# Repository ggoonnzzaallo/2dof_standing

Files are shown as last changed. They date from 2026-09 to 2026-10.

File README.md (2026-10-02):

# Self-righting arm — design package

Current purchased architecture: **XIAO nRF52840 Sense + two PTK 7465 MG servos + one 500 mAh, 1S LiPo**. The user reported all parts ordered on 1 October 2026; see [procurement status](docs/PROCUREMENT_STATUS.md). Train on a computer with MuJoCo and Stable-Baselines3 PPO; run the small exported actor on the XIAO. The **IMU and LiPo charger are already on the XIAO Sense board**, which is attached to the robot's base. No boost converter, external IMU, servo driver board, or separate charger is planned.

This is a prototype design, not a proven self-righting product. **The revised CAD centers the battery, middle link and paddle over the base, surrounds each servo with a matching front-and-rear cage, and supports the far side of each joint with a passive bearing and pin. The delivered non-W servo, OEM horns and battery must be measured before final printing.** The two bearings and pins are proposed additions, not in the user's reported orders. The simulator's servo dynamics and masses are still unmeasured placeholders, not PTK characterization. No physical robot has been assembled or tested, and no trained recovery policy is included. The low-voltage motor cutoff, USB charge interlock, and 100 mA charge-current configuration described in `HARDWARE.md` are firmware requirements, not implemented code yet; implement and test them before untethered battery runs or relying on in-robot USB charging for the 500 mAh pack.

## Package

- [Current PTK parts list and fastener plan](BOM.md)
- [Ordered-parts status and incoming checks](docs/PROCUREMENT_STATUS.md)
- [Controller comparison and IMU location](docs/CONTROLLER_DECISION.md)
- [Servo choice versus SO-100 smart servos](docs/SERVO_DECISION.md)
- [Historical AliExpress shopping plan](docs/ALIEXPRESS_SOURCING.md)
- [Historical DigiKey sourcing audit](docs/DIGIKEY_SOURCING.md)
- [Wiring, commissioning, and design rationale](HARDWARE.md)
- [Onboard voltage monitoring and USB-C charging plan](HARDWARE.md#battery-monitoring-and-charging)
- [Power budget and brownout acceptance test](HARDWARE.md#power-budget-and-brownout-check)
- [CAD assembly](cad/assembly.step), [preview](cad/preview.png), [servo-mount fit coupon](cad/servo_mount_fit_coupon.stl), [horn fit coupon](cad/horn_fit_coupon.stl), [pivot fit coupon](cad/pivot_fit_coupon.stl), [battery-tunnel fit coupon](cad/battery_tunnel_fit_coupon.stl), [measurement sheet](cad/FIT_CHECK.md), and [CAD/printing notes](cad/README.md)
- [Training and deployment pipeline](sim/README.md)
- [Software validation results](sim/validation.json) and [sampled CAD motion check](cad/motion_check.json)

## Design decisions

The serial hinges are **perpendicular**: lower X axis, upper Y axis. Two parallel hinges would concentrate motion in one plane and make general sideways recovery much harder. The supplied reference XML also uses perpendicular axes. The base is free to translate and rotate; it is not attached to the table. Once recovered, the robot stands on a stable platform rather than continuously balancing on an edge. [Reference project](https://github.com/homemadegarbage/SelfRisingRobot), [project article](https://homemadegarbage.com/rl13).

The base footprint remains **70 × 64 mm**; the full upright envelope is about **70 × 66 × 145 mm** because the upper servo cage projects just past one base edge. The joints are at 42 and 87 mm. A centered tunnel under the mounting deck holds the battery; the XIAO and power switch sit on opposite low shelves. The separate battery guard is no longer needed. The earlier **80–90 g** estimate predates the centered, caged structure and must be rechecked from sliced and measured masses. The parametric design allows shrinking after the recovery mechanics are demonstrated.

The [XIAO Sense](https://wiki.seeedstudio.com/XIAO_BLE/) is 21 × 17.8 mm and combines an nRF52840, six-axis IMU, battery input and LiPo charger. It has enough memory for the provided 4,994-parameter actor: **19,976 bytes of float32 weights** plus small working buffers. This is inference only; training stays on the workstation. Select SKU **102010469**; similarly named XIAO boards have different sensors.

The reference [ATOM Matrix](https://docs.m5stack.com/en/core/ATOM%20Matrix) **also has its IMU onboard** and the author reports running the build on a 3.7 V cell. Its documented input is 5 V, and its board documentation does not list an onboard LiPo charger. For this version, the XIAO offers a smaller board footprint and integrated charging; the ATOM retains advantages for reproducing the author's firmware and Wi-Fi user interface. The [detailed comparison](docs/CONTROLLER_DECISION.md) separates verified specifications from prototype assumptions.

The [reference robot](https://homemadegarbage.com/rl13) used PTK 7465 MG servos from one 3.7 V LiPo; the author confirms operation without a boost converter in the article comments. This is direct evidence for the same kind of recovery task, but **not** a manufacturer's 1S operating guarantee. Confirm the exact received servo variant, test it at 4.2, 3.8 and 3.6 V, and update the CAD and simulation with measured dimensions and dynamics before relying on the design.

## Evidence and limits

All three robot-part STLs and four fit-coupon STLs pass watertight-mesh and single-connected-component checks; see `cad/stl_validation.json`.

The provisional PTK CAD solids export successfully; each printed part and fit coupon is one valid connected solid. The upright assembly has no unintended rigid-envelope overlaps. An 81-pose grid over both joints at 20-degree increments from −80 to +80 degrees found no clashes in the checked bodies, bearings and pins. This is **not** a continuous clearance certificate: actual horns, screw heads, nuts, leads, compliance and manufacturing tolerances still require inspection.

The earlier Gymnasium environment check, 1,500 randomized steps and short 512-step PPO training smoke test passed before the PTK geometry update. Exported C inference then agreed with SB3 deterministic inference to better than 1e-5 on 100 test observations. That smoke policy was discarded; the centered `sim/robot.xml` has only been loaded and briefly stepped in MuJoCo, not retrained or rechecked end-to-end.

The next physical milestones are: fit the supplied servo horns; measure travel/torque/lag at 4.2, 3.8 and 3.6 V; demonstrate a scripted rise from each major fall direction; update the model; then train and transfer. If scripted recovery is mechanically impossible from a resting pose, change the contact geometry before spending time on RL.

The USA distributor prices and listing availability in the [earlier FT90M estimate](docs/FT90M_BOM_HISTORY.md) were checked on **27 September 2026**. They are historical estimates, **not the actual cost of the ordered PTK build**. The capacitor and signal resistors remain optional diagnostic additions. The confirmed Pololu and battery order totals, and the still-unknown delivered costs of other purchases, are recorded in [procurement status](docs/PROCUREMENT_STATUS.md).

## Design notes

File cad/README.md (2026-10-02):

# CAD — centered PTK 7465 MG prototype, millimetres

`assembly.step` includes three original printed parts and simplified purchased-part envelopes. Import STEP into Fusion, SolidWorks, FreeCAD or Onshape. The parametric source is `build_cad.py` (CadQuery; generated and checked using 2.8.0). This is newly constructed geometry, not copied from the reference STL files. This revision centers the battery and both moving links over the base, brings each passive bearing support closer to its servo horn, and uses the same two-sided printed cage at both servos.

The CAD now uses a **PTK 7465-family envelope**, but the only dimensioned illustration located is labeled **7465W MG**; the ordered servo is **7465 MG (non-W)**. The [manufacturer's related MG-D listing](https://www.ptkhobby.com/en/sys-pd/234.html) gives the same 23.9 × 12 × 26.6 mm class and 25T output, while the [dimensioned 7465W illustration](https://manuals.plus/ae/1005008789583991) shows a 23.8 mm body, 12 mm width, 31.8 mm ear span, about 27.8 mm mounting pitch, 22 mm main case depth and 30.1 mm overall height including spline. These are **provisional dimensions**, not a verified drawing of the received non-W units. The horn face, boss and mounting interface still require caliper checks. The generated STEP/STL files are a reviewable starting point, not a print-and-assemble guarantee.

| Print one each | Export | Notes |
|---|---|---|
| Base with centered battery tunnel, lower-servo cage and outboard bearing cheek | `base.step`, `base.stl` | Lower plate on bed; the tunnel roof and both cage hoops may need bridging support. Test the cage coupon first. |
| Centered middle link with rotated copy of the servo cage, lower journal and upper outboard cheek | `middle_link.step`, `middle_link.stl` | Stout rounded 12 × 14 mm spine; orient for strength at the lower disk, cage rails and upper fork. |
| Centered upper paddle / horn adapter with outboard journal | `paddle.step`, `paddle.stl` | Rounded 16 × 10 mm shaft and 22 mm wide tip; support the adapter step as needed. |

Four disposable test pieces are generated: `servo_mount_fit_coupon.step/.stl` reproduces the complete front-and-rear servo cage; `horn_fit_coupon.step/.stl` reproduces the adapter face, center access and four radial slots; `pivot_fit_coupon.step/.stl` contains a bearing seat and a separate blind pin bore; `battery_tunnel_fit_coupon.step/.stl` is a 22 mm long tunnel cross-section to test pack clearance and roof bridging. Print the relevant coupons after the servos, battery and proposed pivot hardware arrive, and fill the [incoming measurement sheet](FIT_CHECK.md). The coupons are **not** installed on the robot.

STLs retain the assembly coordinates. Use the slicer's place-on-bed/orient tools for each part; they are not prearranged on a print plate. Start with a 0.4 mm nozzle, 0.2 mm layers, at least 4 walls and 30–40% infill in PLA+ or PETG. Each cage has a front mounting hoop, a rear collar and two 3.5 × 8 mm side rails connecting them; the upper cage is the same geometry rotated 90°. The rear is open for the servo lead, while the side gaps expose the case and mounting fasteners. The lower post and upper cheek have 5 mm axial thickness with tapered roots. Inspect layer direction at cage-to-deck/web joints, disk-to-spine transitions and bearing cheeks. These dimensions improve the load path but have **not** been stress-tested or checked by FEA. Use actual sliced masses in simulation; CAD solid volumes are not printed masses.

The base footprint is 70 × 64 mm; the full upright assembly is approximately **70 × 66 × 145 mm** because the upper servo and rear collar project just past the −Y base edge. Joint origins are `(0,0,42)` and `(0,0,87)` mm; axes +X then +Y at neutral. Both servo assemblies shift 18 mm inward along their output axes, so the moving spine, paddle, battery and joint axes all lie over `(x,y)=(0,0)`. Both cage body openings use **23.9 × 12.0 mm nominal** plus **0.3 mm per-side clearance**; the provisional flange-hole pitch is **27.8 mm**, and the nominal output-axis offset is **6.0 mm** toward one end of the case. These are parameters in `build_cad.py`, not fixed measured truths. Neither SG90 nor FT90M horns are interchangeable with the likely PTK **25T ~5 mm** spline; use the included PTK OEM horns.

The battery slides into the center tunnel from the +X end. Its provisional envelope is 59.5 × 19 × 7.5 mm; the tunnel is 21 mm wide and 10 mm tall above the 3 mm floor, with an end stop at −X. A small cable tie through the two windows at +X retains the pack **at its end**, without squeezing the pouch. The XIAO Sense sits on the +Y low shelf and the Pololu switch on the −Y shelf. This removes the separate battery-guard print. Check the received cell, connector and lead bend radius before final printing; the battery must slide in and out without force. Add insulation under both boards and strain-relieve moving wires.

**Fit-check parameters:** the assumed OEM horn face is 16.5 mm in the original servo-local coordinates; after the 18 mm inward shift, `HORN_FACE=-1.5 mm` in robot coordinates. This is still unmeasured. The now **28 mm diameter, 3 mm thick** printed disk has a 6.8 mm center opening and four radial 2.2 mm slots for a drilled OEM cross/double horn. Use two opposed lateral slots, not the slot under the beam. Each disk has a 12 mm diameter outer hub with a blind 3.05 mm nominal bore for a 3 × 12 mm pin. The fixed cheek has an 8.05 mm nominal bearing pocket, 3 mm deep, with a 6.2 mm rear relief so the shoulder clears the rotating inner race and seats near the outer race. Fit-check horn thickness, slot-to-horn-hole location, screw length, nut/washer clearance, center-screw access, wire exit and spline engagement on physical hardware. Do not print a replacement spline or force a center screw with an unverified thread.

The support is **coaxial** with each servo output: the lower bearing cheek is part of the base and its pin is in the middle link; the upper cheek is part of the middle link and its pin is in the paddle. The pin rotates with its link while the bearing outer ring stays with the parent. This creates a second radial support point across the joint, relieving bending at the servo spline and horn. It is a supported shaft, not a literal double-shear fastener. The upper cheek rises directly from a tapered root on the centered spine, with no long side bridge. The added material changes mass and inertia; use sliced and then measured masses in the simulator.

**Assembly order:** before attaching a horn, slide each servo body into its cage from the output side until the ears meet the front hoop. Route the lead out the open rear; check that its strain relief clears the rear collar without a tight bend. Fasten both ears through the hoop, then install the OEM horn and center screw while there is still straight-on access. The printed outer hub blocks that screwdriver access after assembly, so attach the printed adapter to the horn with its two lateral screws afterward. Seat the bearing by pressing only on its outer ring; if the pocket is loose, retain the **outer ring only** with a small amount of suitable adhesive. Trial-fit the pin to the bearing, then retain the pin in the printed blind hub with a controlled press fit or a tiny amount of suitable adhesive after confirming smooth rotation. Keep adhesive out of the races. The pin should not bottom against the bearing or clamp its inner race axially; trim or change pin length if actual dimensions demand it. Both 3.05 and 8.05 mm printed bores are nominal CAD dimensions, not validated printed fits.

On receipt, measure and record: case length/width/depth; ear span and hole centers/diameters; output-axis offset from the case center; flange face from the back; boss and shaft projection; rear lead and strain-relief envelope; OEM horn arm thickness, radius and hole diameter; OEM center-screw thread/length. Adjust the parameters and rerun the generator before final printing. Check both servos in the full cage coupon: small manufacturing or variant differences matter at a 0.3 mm nominal cavity clearance.

The regenerated **provisional** assembly has no nominal volume intersections in `nominal_clashes.json`. `motion_check.json` checks 81 configurations at 20-degree increments across ±80 degrees, including the outboard bearing and pin envelopes; it does not check a continuous sweep or the real horns, fasteners, leads, ties or print tolerances. Passing this check is not a guarantee of a usable motion range or physical recovery.

The two bearings and pins remain **proposed additions, not included in the user's reported orders**. The centered layout adds no new electrical components. Review it against the delivered PTK horns and battery before buying or printing the full arm. The battery tunnel and wider links add material, so scripted recovery and 1S servo margin still need physical testing.

Regenerate with a separate CAD environment:

```sh
python3.12 -m venv .venv-cad
.venv-cad/bin/pip install cadquery==2.8.0 matplotlib
.venv-cad/bin/python cad/build_cad.py
.venv-cad/bin/python cad/check_motion.py
.venv-cad/bin/python cad/render_preview.py
```

Keep the CAD and training environments separate; their NumPy dependency ranges differ.

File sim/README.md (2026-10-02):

# Training and deployment pipeline

**Centered PTK revision:** `robot.xml` places the battery below the deck, moves the joints to 42 and 87 mm, centers the two moving links, and uses nominal 13 g servo masses. The CAD now also has a front-and-rear printed cage around each servo; its added mass and contact shape are not yet reflected in this primitive model. Weigh and measure the printed assemblies before the transfer-training pass. Servo speed, torque, lag and current behavior at 1S voltage have **not** been measured; `environment.py` retains exploratory placeholder dynamics. Do not train a transfer policy from those numbers until the delivered servos and assembled geometry are characterized.

Use **MuJoCo + Gymnasium + Stable-Baselines3 PPO**. The two-action, small-MLP problem does not justify changing to a GPU robotics stack before basic recovery is demonstrated. SB3 recommends CPU operation for its MLP PPO workloads and supports multiple environments. [Official PPO documentation](https://stable-baselines3.readthedocs.io/en/master/modules/ppo.html), [MuJoCo simulation documentation](https://mujoco.readthedocs.io/en/stable/computation/index.html).

## Supplied runnable starter

- `robot.xml`: free-base, two perpendicular hinges, floor contacts, approximate component masses and primitive collision shapes. Its main joint, paddle, battery, board and switch positions track the centered CAD. The battery tunnel, bearing cheeks, adapters, fasteners and contact details are simplified; it is **not an exact digital twin**. Parent-child collision filtering and physical joint limits must be reviewed as the geometry is finalized.
- `environment.py`: 2 ms physics, 20 ms policy steps; finite torque/speed/lag; command delay, mass, friction and IMU noise randomization; upright, side, diagonal and inverted resets.
- `train.py`: SB3 PPO with separate 64×64 tanh actor/critic, CPU and optional subprocess environments.
- `export_actor.py`: actor-only C export, no neural-network runtime required.
- `check.py`: environment validation, random rollout, short training smoke test, and compiled C-vs-SB3 parity test.
- `validation.json`: actual check results. No useful trained controller has been produced.

From this package's root:

```sh
python3 -m venv .venv-sim
.venv-sim/bin/pip install -r sim/requirements.txt
.venv-sim/bin/python sim/check.py
.venv-sim/bin/python sim/train.py --envs 4 --steps 2000000 --out runs/ppo_seed1
.venv-sim/bin/python sim/export_actor.py runs/ppo_seed1.zip policy.h
```

The version pins record the tested environment rather than a claim that these are the newest releases. The default two million steps is a starting budget, not a convergence prediction. Repeat with independent seeds. The C compiler is required only for `check.py`'s host parity check.

## The servo is not an ideal angle source

The policy sends **target-angle changes**, not joint angles or motor torque. In `environment.py`, each command first passes through 0–40 ms of randomized delay. An internal servo target moves toward it at a finite rate. The simulated servo then compares that target with the **actual simulated joint angle and velocity** and applies a bounded torque; floor contact or gravity can make the joint lag, stall, or be pushed away from the target. This mirrors the division of work on the robot: the PTK servo closes its own position loop, while the XIAO only knows the angle it requested. Actual simulated joint angle is used inside the servo physics and training reward, **not as an input to the policy**.

The present **3–5 rad/s** speed, **0.045–0.070 N·m** torque, gain and delay ranges are placeholders, not measurements of PTK 7465 MG on one LiPo cell. The [related manufacturer's MG-D data](https://www.ptkhobby.com/en/sys-pd/234.html) only give speed at 5 V and above; they do not predict motion at 3.6–4.2 V while pushing against the floor. Before substantial training, mark a horn and film repeatable angle steps from a fixed camera at several battery voltages, first unloaded and then with a representative link/load. Fit command delay, joint angle versus time, steady tracking error and reversal deadband/backlash. Use a known lever/load and brief current measurements to bound usable torque without holding the servo stalled. Temporary video gives angle/speed measurements for calibration; the finished robot does not need joint sensors merely to calibrate the simulator. Compare real and simulated traces for held-out commands, then randomize parameters around the measured range. If large unobserved joint deviations still defeat recovery, consider feedback hardware and retrain with its angle readings.

## Observation/action contract

The 10 float32 inputs, in order, are:

| Indices | Value on both simulator and MCU |
|---|---|
| 0–2 | Unit DOWN vector in the base frame: `R_world_from_base.T @ [0,0,-1]`; upright is `[0,0,-1]` |
| 3–5 | Base-frame gyro in rad/s divided by 10, clipped to ±1 |
| 6–7 | Last commanded target angles divided by 1.3963 rad, clipped to ±1 |
| 8–9 | Previous clipped policy action |

Two outputs are clipped to ±1, multiplied by 0.06 rad and added to the stored joint targets each 20 ms. Clamp targets to ±1.3963 rad (±80°). Convert targets to calibrated servo pulse widths in firmware. Initial targets/actions are zero. Input scale/order, angle signs, timing and hidden-state initialization must match exactly.

There is no `VecNormalize` state to forget during export. The export preserves SB3's deterministic Gaussian mean and final action clipping; it does not introduce an extra output tanh. The actor contains 4,994 floats (19,976 bytes), about 4,864 multiply-accumulates per call plus tanh operations. It fits the proposed MCU comfortably in memory; measure worst-case execution time on the real firmware before committing to 50 Hz.

Actual joint angle and velocity are used for simulated servo dynamics and reward, **not policy observations**, since the selected three-wire PTK servos do not report them. Floor contact is likewise used to score success during training, not passed to the policy. It is fine for a simulator to use these privileged quantities for its reward: the deployed policy only runs inference and does not calculate that reward. A future feedback-servo upgrade requires a changed wiring/model/observation contract.

## Real training sequence

1. **Identify the hardware.** Weigh assemblies and measure COM. Record pulse-to-angle curves, sign, endpoints, no-load and loaded step responses, backlash, battery sag and current at 4.2/3.8/3.5 V. Fit servo dynamics and bound torque; stall torque is not continuous torque.
2. **Make a demonstrably recoverable mechanism.** Find slow scripted or short waypoint sequences for cardinal and diagonal falls. Search safe sequences in simulation, then test under supervision. If necessary change base width, paddle reach or contact shape. Preserve a simple scripted baseline.
3. **Build the simulation fidelity that matters.** Replace primitive contacts with a sensible decomposition of measured printed parts; do not use a single convex hull that fills the arm's open spaces. Match joint stops, base edges, battery deck and bearing-cheek contacts. Retain the floating root. Confirm real and simulated step responses before policy optimization.
4. **Use curriculum if scratch PPO stalls.** Start near upright, then side falls, then inverted starts. Optionally behavior-clone successful scripted trajectories into the actor, then call PPO `.learn(...)` to optimize further. The source project's search/demo-pretrain workflow is useful, but its saved model is not interchangeable with our changed geometry and observations. [Reference repository](https://github.com/homemadegarbage/SelfRisingRobot).
5. **Randomize within measured bounds.** The starter includes mass ±10%, floor friction 0.35–1.0, torque 0.045–0.070 N·m, speed 3–5 rad/s, gain, 0–40 ms command delay and sensor noise. These are placeholder ranges. Add measured backlash/deadband, COM uncertainty, battery-dependent behavior and observation delay before transfer. Avoid deliberately training on physically impossible torque.
6. **Evaluate separate from training.** Use held-out seeds; four side falls, four diagonals, inverted starts and multiple initial joint states; test several surfaces and voltages. Log recovery success within 10 s, recovery time, peak current, stalls and peak contact loads. Require sustained base uprightness, near-home arm, low angular velocity and floor contact. Do not count an airborne or tip-balanced instant as success.
7. **Deploy and compare logs.** Run IMU acquisition/fusion around 200 Hz, policy/PWM target update at 50 Hz. Export only the actor and compare known input/output vectors on the MCU. Then start with restricted motion and expand toward the validated envelope.

## IMU and sim-to-real details still to implement

**The current environment is a software starter, not yet sensor-faithful for transfer.** Its gravity observation comes from MuJoCo's exact base orientation plus noise, while the real robot has only one base-mounted accelerometer/gyro. Real hardware needs a quaternion-based gyro/accelerometer attitude filter and explicit sensor-to-base alignment; the environment must then use the same estimator or model its delay and dynamic errors before training a deployment policy. A normalized raw accelerometer reading is not gravity during a flip. Gate accelerometer correction during strong non-gravitational acceleration, and test recovery through 180-degree orientations. Avoid a roll/pitch formula that changes branches or saturates at 90 degrees. The IMU cannot directly see joint angle, contact or absolute yaw; upright recovery should not depend on absolute yaw.

The 10-input starter has no history or battery observation. If real servo lag creates partial observability, add a short observation history first (and update the exporter), or a battery-voltage feature after calibrating the ADC. A recurrent policy is an option, but makes deployment and reset behavior more complicated. Do not change observation dimensions only on one side.

Firmware board support, sensor filter, PWM calibration, battery sensing, arming, watchdog and servo-power sequencing remain to be implemented. The portable policy exporter is supplied and tested; a board-ready firmware image is not part of this prototype package.

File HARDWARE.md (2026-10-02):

# Hardware and commissioning

**Servo revision (1 October 2026):** Two PTK 7465 MG servos have been ordered. The CAD now uses a provisional PTK 7465-family envelope. The actual non-W servo's mounting ears, horn, pulse mapping, 3.3 V signal response and one-cell current/torque remain incoming checks. The electrical topology below is unchanged. See [procurement status](docs/PROCUREMENT_STATUS.md).

The IMU is the LSM6DS3TR-C chip **on the XIAO nRF52840 Sense PCB**. Mount that PCB rigidly on the base, near the controller envelope shown in `cad/assembly.step`. There is no separate IMU module or IMU wire harness. The reference ATOM Matrix also contains its own IMU (MPU6886). See the [board comparison and parts-count options](docs/CONTROLLER_DECISION.md).

## What the robot can measure

| Device | Available to the XIAO | Role |
|---|---|---|
| **One** onboard LSM6DS3TR-C IMU | Three-axis acceleration and three-axis angular velocity | Estimate base orientation relative to gravity and its rotation rate. Six axes means two three-axis measurements, **not six IMUs**. The IMU is rigidly attached to the base, so it does not directly measure either moving link. [Seeed IMU guide](https://wiki.seeedstudio.com/XIAO-BLE-Sense-IMU-Usage/). |
| XIAO battery-voltage ADC divider | Cell voltage after calibration | Low-battery protection and optional policy input; not a joint or contact sensor. See battery-monitoring details below. |
| Two PTK 7465 MG servos | Commanded PWM targets only | The selected three-wire servos expose signal, power and ground, with no shaft-angle, velocity, load, current or battery-voltage telemetry to the XIAO. They control their own position internally. [PTK's related 7465 MG-D page](https://www.ptkhobby.com/en/sys-pd/234.html). |
| XIAO Sense onboard microphone | Present but unused | It is not required for upright recovery or the current policy. [Seeed board specification](https://wiki.seeedstudio.com/XIAO_BLE/). |

This sensor set is enough to **attempt** the current ten-input policy because its inputs are base gravity direction and angular rate, the last two commanded joint targets and the previous two actions; actual joint angles and contact state are deliberately excluded. It is not full-state feedback. A stalled, back-driven or lagging servo can be far from its commanded target without the controller knowing. If measured recovery trials show this matters, the first sensor upgrade should be two joint-position feedback channels or servos that expose angle telemetry, rather than a second base IMU. Such a change also requires updating the policy observation and training model.

If command-only observations prove insufficient after physical trials, joint feedback would require a different servo or carefully characterized modification. That would change the wiring, observation vector, model and CAD. It is not part of the ordered Rev A hardware; see [servo tradeoffs](docs/SERVO_DECISION.md).

## Power and signals

```text
EFLB5001S25 1S battery / keyed RCY connector
  + ----+---------------------------- XIAO BAT+
        +---- Pololu 2810 VIN
                   VOUT ----+-------- Servo 1 positive
                            +-------- Servo 2 positive
  - ----+---------------------------- XIAO BAT- / GND
        +---------------------------- Pololu GND
        +---------------------------- Both servo grounds

XIAO D0 ---------------- Servo 1 signal
XIAO D1 ---------------- Servo 2 signal
XIAO D2 ---------------- Pololu ON
USB-C ------------------ XIAO programming + onboard charging
```

**The servos are not powered by the XIAO.** At the RCY pigtail, split battery positive into a thin XIAO BAT+ branch and a separate, short power branch through the Pololu switch to both servo red leads. Split battery negative into XIAO BAT−/GND and both servo black/brown leads at the same battery-side junction. Only the two servo signal leads and the switch's ON control lead connect to XIAO GPIOs. The shared ground gives those signals a common reference; the motor current returns directly to the battery junction, not through the controller board. Never connect servo red leads to XIAO 3V3 or 5V/VBUS, and do not route motor current through tiny PCB traces or a solderless breadboard.

Keep the high-current wiring short and secure. No external capacitor or signal resistors are planned in the first wiring layout. Measure the battery voltage at the controller during hard servo direction changes; add a capacitor across the switched servo supply only if measured transients or resets justify one. A capacitor cannot rescue an undersized battery or long resistive power wiring. [Pololu notes that capacitors near its switch can reduce spikes when interrupting large currents](https://www.pololu.com/product/2810).

Leave the **Pololu's physical slide OFF permanently** for normal MCU control; no routine slide movement is needed, including for USB charging. On this particular switch, physical OFF is **not a manual motor disconnect**: D2 HIGH still powers the servos. Physical ON forces them on, overriding D2. With physical OFF and D2 LOW or floating, the servo rail is off. Initialize D2 LOW before any PWM setup. Before cutting servo power, stop both PWM outputs and set their pins low; keep them low until servo power is restored. This avoids intentionally driving an unpowered servo through its signal pin. Check the actual servos for back-powering; two optional 1 kΩ series resistors can limit that current if it occurs, but do not replace correct sequencing. [Pololu 2810 documentation](https://www.pololu.com/product/2810).

## Battery monitoring and charging

**The XIAO Sense can read the battery without extra hardware.** Its onboard voltage divider presents a reduced battery voltage to ADC pin **P0.31**; drive **P0.14 LOW** to enable that reading. The reviewed schematic uses 1 MΩ/510 kΩ divider resistors, but board revisions and ADC settings can change the conversion, so calibrate the reported volts against a multimeter at the actual BAT pads. Do not assume a raw ADC count is directly the cell voltage. [Seeed's pin/charging documentation](https://wiki.seeedstudio.com/XIAO_BLE/) specifically warns that driving P0.14 HIGH can put P0.31 at its input limit during charging; keep P0.14 LOW while reading and never drive it HIGH while charging. Raw Nordic pin names are not necessarily Arduino D-pin numbers. The PTK servos have ordinary PWM command inputs and **no battery-voltage telemetry**; their three wires cannot report cell state.

The planned firmware will sample battery voltage during servo operation, filter out single-sample noise, and latch a low-battery fault if the voltage at the XIAO falls below an initial **3.6 V loaded threshold** for a short sustained interval. On fault it will stop PWM, pull D2 LOW to disconnect servo power, indicate the fault with the XIAO's onboard LED, and sleep. The threshold and filtering require calibration from the loaded bench test below. The ADC is adequate for tracking pack voltage and triggering a cutoff, but voltage under variable servo load is **not a precise charge-percentage gauge**; it can also miss millisecond dips. **This cutoff firmware has not yet been implemented.** The battery remains connected to the MCU when servos are disabled; **unplug the RCY for storage and a true power-off**.

**Routine charge without unplugging the battery:** the XIAO's [BQ25101 single-cell charger](https://www.ti.com/product/BQ25101) charges the connected pack toward **4.2 V** through the robot's USB-C port. The Pololu slide stays physically OFF. Charge-mode firmware must stop servo PWM, command D2 LOW, and keep the servo rail disabled whenever USB VBUS is present. The nRF52840 supports [USBDETECTED/USBREMOVED events](https://docs.nordicsemi.com/r/bundle/ps_nrf52840/page/usbd.html) without another sensor component. Verify that servo VOUT is off during bring-up. Merely putting the slide in OFF is insufficient if D2 remains HIGH. If the servo rail remains on, the servos can move and draw from the battery while charging, delaying charge completion or triggering the charger's fixed ten-hour safety timer. It does not route servo current through the XIAO, but it is not the intended charge state. **The charge interlock firmware is not yet implemented**, so do not rely on automatic motor shutoff in the present prototype.

For in-robot charging, [Seeed documents](https://wiki.seeedstudio.com/XIAO_BLE/) configuring **P0.13 as an output driven LOW** for approximately **100 mA**, or as a high-impedance input without pulls for approximately **50 mA**. In a Seeed Arduino-core sketch, the 100 mA setup is `digitalWrite(P0_13, LOW); pinMode(P0_13, OUTPUT);`; keep that state for the charging session. This is a firmware setting, not a physical switch or battery-voltage sense pin. At 100 mA (0.2C), an empty 500 mAh pack needs at least about five hours plus the voltage-taper phase. The 50 mA setting is approximately 0.1C and could hit the [charger's fixed ten-hour safety timer](https://www.ti.com/product/BQ25101) before completing. The charger IC itself is specified for a maximum of **250 mA**, and Seeed exposes only the approximately 50/100 mA settings on this board, so **500 mA cannot be selected by software on the XIAO**. The XIAO's charge LED indicates charging activity; verify final battery voltage rather than treating the LED alone as a complete fuel gauge. **Do not apply battery voltage to 3V3 or 5 V to BAT.** Unplug the RCY only for long-term storage or a true hardware power-off, not for routine charging.

## Power budget and brownout check

Seller data for the [PTK 7465 MG family](https://manuals.plus/ae/1005008789583991) reports about **1 A stall current per servo at 4.8 V**. That is only a provisional sizing comparison for two servos (about 2 A), **not** a measurement or guaranteed limit for the purchased non-W units at 3.6–4.2 V. The selected [500 mAh, 25C battery](https://www.horizonhobby.com/product/1s-3.7v-500mah-25c-li-po-battery-jst-rcy/EFLB5001S25.html) advertises a nominal 0.5 Ah × 25 = **12.5 A discharge rating**, above the comparison load on paper. A C rating does not specify voltage sag at the board, connector loss, cell aging, or how long the servos can sustain a mechanical stall. Measure peak draw and sag with the actual pair.

The [Pololu 2810 LV switch](https://www.pololu.com/product/2810) is rated for single-cell voltages and lists 3 A continuous at its 55 °C reference point. The XIAO's [schematic](https://files.seeedstudio.com/wiki/XIAO-BLE/Seeed_Studio_XIAO_nRF52840_PDF.pdf) instead shows a **3.3 V, 250 mA regulator** for its electronics. This is why the servo-power split must occur **before** the XIAO: two servos would exceed that regulator by a wide margin. The regulator also needs input headroom; when the shared battery sags near the end of a run, the 3.3 V rail can dip even though the motors do not draw through the board. The [regulator datasheet](https://www.sg-micro.com/product/SGM2040) gives low dropout under specified conditions, but it does not guarantee behavior for this unmeasured battery/harness and simultaneous servo load.

For the first measurement, use a **DC multimeter**, two thin insulated temporary sense wires, and clips. With the battery **unplugged**, solder one sense wire to the XIAO-side BAT+ joint and one to its GND joint; insulate and strain-relieve both so no clip can short the tiny pads or snag a moving link. Put the meter in **DC-volts mode, in parallel** across those wires (red to BAT+, black to GND). Secure the robot's base, run a repeatable two-servo motion, and watch the voltage while the arms move. To check the regulated rail too, add a **third temporary sense wire to XIAO 3V3 while power is disconnected**, then repeat with the meter's red clip on that wire and black still on GND; a second meter lets you observe both at once. Do **not** use the meter's current/A jack across the battery. A meter with MIN/MAX is helpful for slow sag, but many meters miss millisecond dips. A two-channel oscilloscope at the same test wires is the follow-up tool if resets occur or exact transient minima matter. The robot's built-in battery ADC can log voltage during later untethered tests after calibration, but it can miss brief dips too. [Seeed documents the BAT measurement pins and the required P0.14 LOW state](https://wiki.seeedstudio.com/XIAO_BLE/).

Before untethered operation, test around 4.2, 3.8, and 3.6 V cell voltage while commanding both servos through the fastest intended reversals and brief high-load motions; do not hold a servo at stall. As a conservative prototype acceptance target, the **3V3 rail should stay above 3.2 V and the controller should never reset** during those tests. That 3.2 V value is a design target, not the chip's published reset threshold. If it fails, first improve the battery connector, wiring and cell choice or raise the loaded-voltage cutoff; then consider the optional capacitor for short transients. A capacitor will not fix sustained sag.

**Do not operate this design below 3.0 V at the cell.** The PTK servo's *published* lower operating limit is around **5 V** on the [manufacturer's related 7465 MG-D page](https://www.ptkhobby.com/en/sys-pd/234.html), so **all direct 1S operation is outside that rating**, despite the reference robot's 3.7 V success. The XIAO's 3.3 V regulator cannot maintain a 3.3 V output from a battery below 3.3 V, so a reset or unstable sensing is possible. The selected single-cell LiPo should be shut down well before 3.0 V; [Horizon Hobby's LiPo equipment guidance](https://www.horizonhobby.com/on/demandware.static/-/Sites-horizon-master/default/Manuals/EFLU02050_MANUAL_EN.pdf) uses a 3.0 V-per-cell low-voltage cutoff. Our initial **3.6 V loaded servo cutoff** is intentionally earlier to preserve regulator headroom and battery life, pending measurement. Raise that cutoff if recovery weakens sooner. The cutoff firmware is still a required implementation, and the battery should be disconnected for storage; do not assume the selected RC battery includes its own low-voltage protection.

Use a watchdog and explicit arming state. Charge/program mode, invalid sensor data, stale control loop and low voltage should leave D2 low. Start with a USB command to arm during bench development, then add a deliberate untethered arming gesture/button behavior. No wireless link is needed during normal operation.

## Why 500 mAh, and estimated runtime

The 500 mAh EFLB5001S25 was a **conservative prototype choice**, not the smallest proven pack. Its stated 25C discharge rating corresponds to 12.5 A on paper, above the PTK-family's approximate 2 A combined 4.8 V stall-current comparison. It has a matching RCY connector and dimensions for the current CAD, but at roughly 14.5 g and 59.5 × 19 × 7.5 mm it is a major driver of base size. The reference robot uses 220 mAh. A smaller, suitably high-discharge cell may be better after measuring actual recovery pulses and voltage sag.

Runtime cannot be predicted from stall current or capacity alone: it depends on how frequently the policy moves the joints, how hard it pushes on the floor, voltage sag, and the chosen 3.6 V loaded cutoff. The purchased PTK pair has **no verified 1S current profile**. [Seeed lists 10.38 mA](https://files.seeedstudio.com/wiki/XIAO/Seeed-Studio-XIAO-Series-SOM-Datasheet.pdf) for a normally running XIAO Sense. For planning only, assume **300–400 mAh usable** before the early voltage cutoff and divide that by measured *average total battery current*:

| Average current, including both servos and controller | Illustrative runtime to cutoff |
|---:|---:|
| 0.25 A | 1.2–1.6 h |
| 0.5 A | 36–48 min |
| 1.0 A | 18–24 min |

Those are arithmetic scenarios, **not measured endurance claims**. As a first planning range for repeated active recoveries, expect tens of minutes to about an hour, then replace this estimate with battery-side current logging over representative episodes. A stationary upright robot may last much longer. The 500 mAh pack also takes at least about five hours plus taper on the XIAO's 100 mA charger; a smaller cell would improve both size and charging time if it passes the loaded-voltage test.

## Servo selection and limits

The [manufacturer's related PTK 7465 MG-D page](https://www.ptkhobby.com/en/sys-pd/234.html) specifies a 23.9 × 12 × 26.6 mm package, 25T ~5 mm output spline and about 5–8.4 V operating range. Family listings report approximately **3.8 kg·cm stall torque** and **0.11 s/60° no-load speed at 5 V**; those are neither continuous torque nor 1S performance figures. The [reference robot](https://homemadegarbage.com/rl13) used PTK 7465 MG on one cell and the author reports 3.7 V worked without boost. Verify the purchased non-W units and XIAO's 3.3 V control signal on the bench. If the servos weaken unacceptably as the cell discharges, reconsider power architecture based on measurements.

The simulation's **0.045–0.070 N·m torque limit and 3–5 rad/s speed** are conservative design assumptions to replace with measurements. They are not manufacturer continuous-duty ratings. Avoid using the reference model's 1 N·m actuator limit for these micro servos.

PTK-family listings commonly describe **500–2500 µs for about ±90°**, but variant-specific center and endpoint settings differ. Start with the horn removed and a small **1450–1550 µs** sweep at 50 Hz; measure angle and direction, then widen gradually and set software stops for the actual mechanism. Do not assume the full advertised ±90° is safe with the printed links. The proposed robot joint range remains ±80° pending clearance and wire-loop checks. Later test whether a higher pulse refresh rate gives any benefit; a 50 Hz command rate matches the current policy loop.

These servos provide no external joint-angle feedback. Firmware stores commanded targets; it does not know the actual shaft angle under impact or stall. Training must model lag, backlash and load effects, and policy observations must not secretly use simulator joint encoders. The IMU belongs on the base so its orientation measures platform recovery.

## Mechanics and order of work

At a hypothetical 100 g assembled mass, a simple weight moment about a 35 mm base edge is approximately **0.034 N·m**. The centered reinforced design has not been weighed; this is a sizing example, not a mass prediction or proof that the actuator can execute a recovery trajectory. Floor contact, paddle reach, dynamic impulses and orientation can make the required joint torque much larger. The upper joint's job includes pushing on the floor, not merely lifting its own paddle.

1. Print the servo, horn and pivot fit coupons; check the case, flange holes, actual horn, bearing and pin. Measure the delivered battery as well. Correct CAD dimensions before printing the complete set.
2. Center one unloaded servo at its measured neutral. Install the correct OEM horn and output screw; establish angle direction and pulse calibration. Repeat for the second servo.
3. Assemble the two ear mounts and the two lateral horn adapters using the BOM. Keep screw ends and nut flats out of moving envelopes. Trim excess screw projection if required.
4. Slide the battery into the centered tunnel from the +X end. Retain it at the end with a tie through the two side-wall windows; do not compress or abrade the pouch. Secure the XIAO on the +Y shelf and the switch on the −Y shelf, insulate their undersides, confirm USB-C and slide access, and document sensor-axis orientation.
5. Wire and polarity-check with the battery disconnected. Test the MCU from USB first with the servo supply disabled. Then energize one servo on a current-limited bench supply, followed by both. Check voltage sag during direction reversals.
6. Test full intended travel slowly while supported. Then try four cardinal side falls, diagonal falls and inverted starts on a controlled surface. Start with scripted slow motion and a small search over safe waypoint sequences.
7. Weigh each moving assembly, measure COM, current, loaded response and floor friction. Feed those values back into MuJoCo before substantive policy training.

The base does not have arbitrary soft rubber feet: their traction and compliance would change the contact model. Begin on one repeatable hard surface, then randomize/test additional surfaces. The paddle contact edge and base width are the main geometry tuning parameters. If a pose wedges into a stable resting configuration from which neither joint can create a useful contact force, redesign that geometry; RL cannot remove the physical constraint.

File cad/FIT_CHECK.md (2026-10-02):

# PTK 7465 MG incoming fit check

This sheet distinguishes **provisional CAD inputs** from dimensions measured on the two delivered non-W servos. Fill both measured columns before changing `build_cad.py` or printing the final base and link. The 7465W drawing and related MG-D page are useful family references, but neither establishes the exact dimensions of the purchased units.

| Feature (mm unless stated) | Current CAD input | Servo 1 measured | Servo 2 measured | Where used |
|---|---:|---|---|---|
| Main body length along mounting-hole line | 23.9 | — | — | `BODY_L` |
| Main body width | 12.0 | — | — | `BODY_W` |
| Main body depth, back to case top | 22.0 | — | — | `BODY_DEPTH` |
| Ear/flange overall span | 31.8 | — | — | `FLANGE_SPAN` |
| Ear mounting-hole pitch | 27.8 | — | — | `MOUNT_PITCH` |
| Mounting-hole diameter | 2.0 nominal | — | — | Check M2 clearance and flange holes |
| Output axis from body midpoint toward front end | 6.0 | — | — | `OUTPUT_OFFSET_Z` |
| Front flange face from case back | 18.4 | — | — | `FLANGE_FROM_BACK` |
| Ear thickness | 1.6 assumed | — | — | `FLANGE_T` |
| Body insertion through front hoop and rear collar | 0.3 clearance per side in both openings | — | — | Full `servo_mount_fit_coupon` cage; no case compression |
| Rear lead and molded strain relief beyond case | not established; rear of cage remains open | — | — | Route without pinching or sharp bend |
| Access to both ear fasteners with servo seated | required | — | — | Front hoop and two side rails |
| Shaft/spline outside diameter and tooth count | ~5.0, 25T | — | — | OEM horn only; no printed spline |
| Boss maximum diameter and projection from case | 11.0 × 4.4 assumed | — | — | `servo()` envelope |
| Shaft tip from case back | 30.1 nominal | — | — | `servo()` envelope |
| OEM horn face before / after the 18 mm inward servo shift | 16.5 assumed local / −1.5 robot coordinate | — | — | `AXIAL_SHIFT`, `HORN_FACE` |
| OEM horn thickness, arm width and usable hole radius | not established | — | — | `cut_adapter()` slots and `horn` envelope |
| OEM center-screw thread and usable length | not established | — | — | Use supplied screw; do not force an M2 substitute |
| Center screw installable before the printed hub covers access | required | — | — | `outboard_hub_x()` assembly sequence |
| Bearing OD × bore × width | MR83ZZ 8 × 3 × 3 | — | — | Outboard support pocket at both hinges |
| Actual dowel diameter × length | nominal 3 × 12 | — | — | Blind hub bore and bearing bore at both hinges |
| Printed bearing seat / dowel-bore fit | CAD diameters 8.05 / 3.05 | — | — | `pivot_fit_coupon` before full print |
| Axial freedom and rotation with pin seated | no side preload or rubbing | — | — | Opposite-side support at each joint |
| Servo pulse center, safe range and direction | 1500 µs trial center; ±80° design goal | — | — | Firmware and `sim/robot.xml` joint limits |

Battery and base checks for the centered layout: verify the actual cell length, width, thickness, connector end, and bend radius against the **67 × 21 × 10 mm nominal tunnel**. The retaining tie must contact an end stop or protective connector area, not the LiPo pouch face. Check XIAO USB-C access on the +Y shelf, switch access on the −Y shelf, and wire slack through both joint sweeps.

Print [servo-mount fit coupon](servo_mount_fit_coupon.stl), [horn fit coupon](horn_fit_coupon.stl), [pivot fit coupon](pivot_fit_coupon.stl), and [battery-tunnel fit coupon](battery_tunnel_fit_coupon.stl) before the full parts. The servo coupon now contains the complete shared cage: verify that each actual servo slides through both hoops, seats against the front mount without case compression, exposes both ear fasteners, and allows its lead and strain relief to leave the open rear. Check horn attachment, bearing seat, pin retention and battery slide fit without driving the arm. If a coupon needs filing to fit, change the CAD parameter rather than using filing as the final design. Check that both bearing axes line up with their servo shaft axes and that the links rotate freely without axial preload. With the assembled joints unpowered, gently side-load each link and inspect the cage-to-deck/web joints, rail joints, cheek roots and disk-to-spine transitions for visible flex or layer cracking before powered tests. Record any interference from screw heads, leads or the rotating horn; the current motion check omits those items.

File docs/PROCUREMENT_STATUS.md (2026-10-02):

# Procurement status — 1 October 2026

The user reports **all Rev A robot components ordered**. The later opposed-pivot CAD revision adds two bearings and two dowel pins that have **not** been reported ordered. This records what is known from the conversation; it is not a delivery or inspection record. Do not reorder parts solely because a historical sourcing page still has purchase links.

| Component | Reported status | Evidence and remaining check |
|---|---|---|
| PTK 7465 MG servos, two | Ordered, per user | Exact listing, price, manufacturer suffix, included horns, center screws, spline, flange and body dimensions have not been supplied. Confirm these on receipt. The CAD now uses a provisional 7465-family envelope; do not silently treat 7465W or MG-D specifications as measured non-W dimensions. |
| E-flite EFLB5001S25, 500 mAh 1S 25C LiPo | Two ordered | User supplied a checkout image showing two units, $28.97 total with shipping. Check connector polarity and cell condition on arrival. One cell is used in the robot; the second is spare. |
| Pololu 2810 LV Mini MOSFET Slide Switch | Two ordered, backordered | User supplied a sales-order image showing two units. One is used; one is spare. |
| Pololu 2181 male JST-RCY lead | Two ordered, backordered | Same sales order. One is used; one is spare. The Pololu order total for both product lines was $23.44 with shipping and tax. |
| XIAO nRF52840 Sense and remaining consumables/fasteners | Ordered, per user's overall report | Exact seller, variant, quantities and paid amounts were not supplied. Verify the board says **Sense** and has the onboard IMU; check fasteners against the received servo ears and horns. |
| MR83ZZ bearings, two; 3 × 12 mm dowel pins, two | **Proposed; not ordered** | New opposite-side pivot supports. Review the [revised CAD](../cad/README.md) and measure actual servo/horn spacing before purchase; direct candidate links are in the [BOM](../BOM.md). |

The **known checkout totals** are $23.44 (Pololu) plus $28.97 (two batteries), or **$52.41**. This is not the project's total: servo, controller and remaining order costs are unknown. The original under-$100 goal cannot yet be assessed from recorded receipts. Do not publish personal details from order screenshots in this repository.

## Incoming checks before assembly

1. Photograph or measure the received PTK servo's label and dimensions, spline and supplied horn/center screw. Also measure the battery and connector against the new centered tunnel. Print the [small fit coupons](../cad/README.md), including the pivot coupon if adding the opposed supports, and update `cad/build_cad.py` from actual measurements before final printing. The current PTK geometry is provisional.
2. Confirm connector polarity with a multimeter before connecting the battery. Keep motor current off XIAO power traces; the battery feeds the XIAO and, separately through Pololu 2810, both servo power wires.
3. Characterize one servo, then both, at battery voltages near 4.2, 3.8 and 3.6 V. Record current, voltage sag, travel, unloaded and loaded step response, and whether a scripted rise succeeds. The reference robot's one-cell success is useful evidence, but the PTK servo is not guaranteed by a published 1S rating.
4. Update the servo ranges in `sim/` from the measured PTK data before substantial RL training. The current numbers are placeholders and should not be treated as measured PTK performance.
5. Implement and verify firmware servo cutoff, USB charging interlock and charge-current configuration before relying on in-robot charging or unattended operation. These are still requirements, not finished features.

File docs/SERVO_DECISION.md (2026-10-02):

# Servo choice: joint readback versus smart-servo precision

**Decision update, 1 October 2026:** The user ordered **two PTK 7465 MG** servos, matching the [reference self-righting robot](https://homemadegarbage.com/rl13), whose author confirms operation from one 3.7 V LiPo without boost. The earlier FT90M recommendation and comparison below are retained as design history; FT90M is **not** the chosen or ordered servo. The CAD and MuJoCo geometry now use provisional PTK dimensions, while actual non-W dimensions, horn fit and one-cell servo dynamics still require incoming inspection and bench measurement.

The SO-100 arm uses **FEETECH STS3215** serial bus servos. They are a different actuator class from a three-wire RC servo or the four-wire FT90M-FB. The choice is about actuator control and joint observability, not cable count.

| Choice | What the controller receives | Power and physical fit | Rev A implication |
|---|---|---|---|
| FT90M, superseded candidate | PWM angle command only. The servo's internal potentiometer closes its own loop; XIAO cannot read actual angle. | FEETECH rates it for 3–8.4 V, so a 1S cell can power it directly. Micro-servo size. | Historical datasheet-supported option; not purchased for Rev A. |
| PTK 7465 MG, ordered Rev A | PWM angle command only; no joint-angle telemetry exposed to XIAO. | Reference builder reports 3.7 V success, but [related PTK MG-D specifications](https://www.ptkhobby.com/en/sys-pd/234.html) start around 5 V; direct 1S is outside published range. Provisional body envelope is 23.9 × 12 mm with 25T ~5 mm spline. | Better evidence for this particular recovery mechanism, subject to measurements across the cell voltage range and OEM horn fit. |
| FT90M-FB, optional substitution | PWM command plus a separate **analog angle feedback** wire. No digital speed/current/temperature reports. | FEETECH rates it for 3–8.4 V, with a 23.2 × 12 × 25.5 mm case and 12.5 g weight. Same 1S supply concept; two ADC inputs and wiring changes are needed to consume feedback. | Useful if real joint angle is valuable to the policy. It does **not** make the actuator's gears, internal loop, or output precision better merely by exposing the signal. |
| STS3215, SO-100 actuator | Half-duplex TTL serial command and digital reports of position, speed, load, voltage, current, and temperature. Its magnetic encoder has 12-bit electronic resolution (0.088° per count), and the sheet specifies ≤0.5° gear backlash versus ≤2° for the FT90M. Resolution and backlash specifications are **not** guaranteed loaded positioning accuracy. | Manufacturer rates 4–7.4 V, with undervoltage protection below 4 V; 45.2 × 24.7 × 35 mm, about 55 g **each**. Two alone weigh about 110 g before structure, battery and controller. | Requires redesigned CAD, higher-power battery architecture (or suitable boost), bus interface, and a new power/brownout analysis. Do not substitute into the existing BOM or printed mounts. |

The [SO-100 parts list](https://github.com/TheRobotStudio/SO-ARM100/blob/main/SO100.md) lists STS3215 servos at about $14–15 each and a separate motor-control board. That price is a reference-project estimate, not a delivered US quote. The [STS3215 manufacturer's sheet](https://files.seeedstudio.com/products/Feetech/108090023_STS3215-C001_Datasheet.pdf) gives the electrical, mechanical and telemetry details above. Its 4 V minimum and below-4 V protection leave almost no useful margin on a 1S LiPo: a charged cell starts at 4.2 V, and most of its discharge occurs below 4 V. The SO-100 uses an external power supply; its actuator choice should not be transplanted into this onboard 1S design without redesigning the power system.

**Historical decision, superseded:** The first version chose FT90M as a datasheet-supported 1S baseline and considered FT90M-FB if readback were worth two extra wires. The current purchased PTK servos remain ordinary three-wire PWM servos with no exposed joint-angle feedback. Bench-test travel, loaded response and self-righting with a scripted maneuver before treating the selected hardware as validated. A future smart-servo revision would be a different mechanical and electrical design.

The [FT90M specification](https://evelta.com/content/datasheets/501-FT90M.pdf) and [FT90M-FB product page](https://www.feetechrc.com/2kg-cm-digital-steering-gear-ft90m-fb.html) provide the two micro-servo operating ranges and dimensions. If we use joint-angle observations, update the MuJoCo policy and onboard firmware together; do not give the simulated policy perfect joint position while the physical policy sees only prior commands.

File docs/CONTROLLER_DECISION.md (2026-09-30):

# Controller and IMU decision

The reference robot uses an **M5Stack ATOM Matrix**. It already contains an **MPU6886 six-axis IMU** (a 3-axis accelerometer and 3-axis gyroscope), and its Arduino firmware reads that sensor with `M5.IMU.getAccelData(...)` and `M5.IMU.getGyroData(...)`. The reference code drives the two servos from GPIO 26 and 32. The author's build uses a 3.7 V LiPo and reports that it worked without a boost converter, even though M5Stack's published ATOM Matrix input specification is 5 V. We should treat that as a successful experiment on that build, not proof of operation over every cell voltage and load. [Project article](https://homemadegarbage.com/rl13), [firmware](https://github.com/homemadegarbage/SelfRisingRobot/blob/main/Arduino/robo03/robo03.ino), [M5Stack specifications](https://docs.m5stack.com/en/core/Atom-Matrix).

Our proposed **Seeed XIAO nRF52840 Sense** likewise puts the IMU **on the controller board itself**. The IMU is the **LSM6DS3TR-C**. The board also contains an nRF52840 processor, battery pads, a charger IC, and USB-C. The Sense board has a 21 × 17.8 mm footprint. The ordinary XIAO nRF52840 without “Sense” has **no IMU**; its smaller name difference matters. [Seeed's board comparison and pin map](https://wiki.seeedstudio.com/XIAO_BLE/).

**Exact purchase variant:** the linked [standard XIAO nRF52840 Sense, SKU 102010469](https://www.seeedstudio.com/Seeed-XIAO-BLE-Sense-nRF52840-p-5253.html). The [Sense Plus, SKU 102010694](https://www.seeedstudio.com/Seeed-Studio-XIAO-nRF52840-Sense-Plus-p-6360.html) keeps the same IMU and charger but exposes extra solder pads/GPIOs, which this two-servo robot does not need. It is a reasonable substitute only after checking the underside battery-pad layout and mount clearance. The [non-Sense XIAO nRF52840, SKU 102010448](https://www.seeedstudio.com/Seeed-XIAO-BLE-nRF52840-p-5201.html), has no IMU and is unsuitable without adding one.

## Where the IMU is in our robot

The XIAO Sense board is fastened rigidly **on the base platform**, at approximately `(x=23, y=18, z=6)` mm in `cad/assembly.step`. The IMU chip is soldered onto that board; it is not a separate breakout board or another BOM line. It measures the **base's** accelerations and angular rates. Firmware combines those measurements to estimate which way gravity points relative to the base. The policy uses that direction to decide how to move the arm. There is no external IMU cable. Record the final board orientation during assembly so the firmware can map chip axes to robot axes. A thick soft mount would let the board tilt separately from the base and corrupt the estimate.

```text
   On the base: XIAO nRF52840 Sense PCB
   ├── nRF52840 MCU       → runs the trained policy at 50 Hz
   ├── LSM6DS3TR-C IMU    → senses base motion (accel + gyro)
   ├── BQ25101 charger    → charges a standard 1S LiPo over USB-C
   ├── D0 and D1          → servo PWM signals
   └── BAT pads           → battery input

   Elsewhere: battery → servo-power switch → two servos
```

An accelerometer alone cannot reliably indicate gravity during a fast flip because it also sees movement acceleration. Firmware needs an attitude filter using the gyro and accelerometer, with a well-defined board-to-base axis mapping. The simulator's projected-gravity observation is currently idealized; `sim/README.md` calls out this remaining transfer step.

## Why select XIAO Sense for this version?

| Question | Reference ATOM Matrix | Proposed XIAO nRF52840 Sense | Practical implication |
|---|---|---|---|
| Is the IMU onboard? | Yes, MPU6886. | Yes, LSM6DS3TR-C. | **No IMU component-count advantage** either way. |
| Board envelope | 24 × 24 × 13.8 mm, 7.3 g including its case. | 21 × 17.8 mm board footprint. | XIAO's footprint is about **35% smaller**; actual assembled robot footprint is currently set mostly by the battery, so this does not shrink the base by 35%. |
| Processor | ESP32 up to 240 MHz, with Wi-Fi. | Cortex-M4F at 64 MHz, with BLE. | Both can plausibly run this small policy; on-device timing still needs measurement. ATOM has substantially more compute and an existing Wi-Fi interface. |
| Single-cell supply | Official input: 5 V. Author reports direct 3.7 V worked. | Dedicated 1S battery pads and onboard charging circuit. | XIAO provides a documented battery/charging arrangement without adding a boost converter. |
| Charging | Reference battery bundle includes external USB chargers. No onboard LiPo charger is listed in the ATOM Matrix specifications. | Onboard BQ25101 charger through USB-C at about 100 mA with firmware configuration. | XIAO allows in-robot charging without a separate charging board or unplugging the pack. Firmware must disable servo power while USB is present; see `HARDWARE.md`. |
| Development convenience | The reference firmware, button, 5×5 LED display and Wi-Fi web interface already exist. | New IMU, PWM, filter and policy firmware must be written. | **ATOM wins for reproducing the reference quickly.** XIAO is my choice for the smaller onboard-charge version. |

The XIAO is therefore **better for our selected battery and component-count goal**, not universally better. The reference ATOM is a valid fallback if replicating its firmware and Wi-Fi calibration UI matters more than the charging integration. Swapping controllers changes the mount, wiring and firmware, but not the basic two-joint robot concept. Do not assume an ATOM S3 or another XIAO version has the same IMU or power circuit without checking its exact SKU.

## How far can we reduce the parts count?

The minimum active hardware is **one XIAO Sense, two servos and one 1S battery**. A matching battery connector/pigtail and wires are still needed for a removable pack. The XIAO already supplies the processor, IMU, regulator and USB charger; it requires **no separate Raspberry Pi, IMU breakout, servo driver board, boost converter or charging board** for this design.

The recommended Rev A BOM adds **one Pololu servo-power switch** to the minimum active hardware. The capacitor and two signal resistors are optional troubleshooting parts, not necessary purchases for the first build:

| Item | Why consider it | If omitted |
|---|---|---|
| Servo-power switch — **included** | MCU can turn servo power off on a low-battery fault and while charging/programming. | Servos remain connected whenever the battery is plugged in. The pack must be unplugged for a true shutdown; USB charging needs careful testing with the permanently attached servo rail. |
| 1000 µF capacitor — **optional** | Buffers brief servo-current spikes near the load. | Start without it; add if loaded voltage measurements show dips/spikes or the MCU resets despite short, sound wiring. |
| Two 1 kΩ resistors — **optional** | Limit current that could enter unpowered servo signal inputs. | Use correct firmware power sequencing and verify with the actual servos. Add only if back-powering is observed. |

I recommend **retaining the switch for the first build**. It is the one added board that allows the firmware to cut motor power. Wire the servo signals directly for now and measure supply behavior under load. A simple mechanical slide switch may be smaller/cheaper, but it gives up firmware-controlled shutdown. Those are design choices, not one-for-one substitutions.

Separately, the current **500 mAh battery** is the largest footprint driver. The reference uses a 220 mAh pack. A properly rated smaller cell could materially shrink the platform, but it will shorten runtime and must be checked for stall-current delivery, connector, 4.2 V charge chemistry and physical protection before redrawing the base.

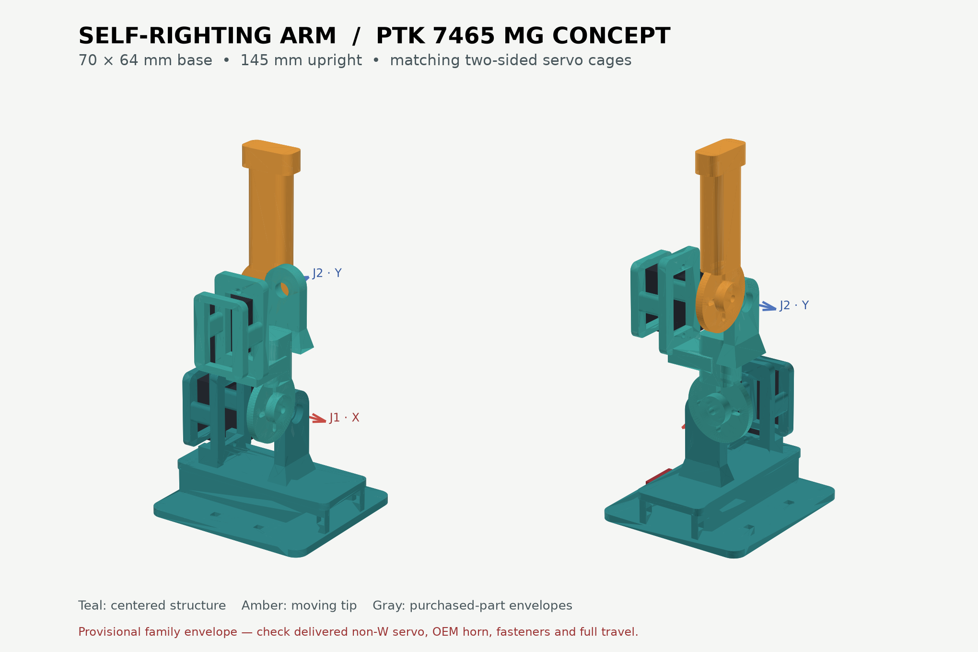
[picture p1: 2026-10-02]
cad/preview.png

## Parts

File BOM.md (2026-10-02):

# Centered reinforced build BOM — PTK 7465 MG

The user reported the original electronics and servos ordered on 1 October 2026. **The two pivot rows below remain proposed and unpurchased.** The centered, two-sided servo cages are printed into the existing structural parts and add no purchased components. Check the revised CAD and received servo, horn and battery dimensions before ordering the pivots or printing full parts. Exact seller/receipt details for the controller, servos and miscellaneous hardware remain to be confirmed against deliveries. The older FT90M shopping estimate is retained separately in [FT90M BOM history](docs/FT90M_BOM_HISTORY.md).

| Component | Bought / used | What it does | Source / status | Incoming check |
|---|---:|---|---|---|
| **PTK 7465 MG** three-wire positional micro servo, non-W | 2 / 2 | Moves the two serial arm joints. Each servo closes its own position loop; the XIAO commands a target by PWM but cannot read actual joint angle. | User reports ordered. [Reference robot](https://homemadegarbage.com/rl13) used this model from one LiPo cell. Exact seller, delivered price and contents were not supplied. | Confirm label/suffix, body and flange measurements, 25T ~5 mm spline, supplied horn and center screw. Measure 1S speed, load response and current. |
| **Seeed XIAO nRF52840 Sense**, SKU 102010469 | 1 / 1 | Runs the onboard policy and PWM; its built-in six-axis IMU senses base motion, ADC reads battery voltage, and onboard charger charges the cell through USB-C. | User reports all parts ordered; exact controller receipt not supplied. [Manufacturer guide](https://wiki.seeedstudio.com/XIAO_BLE/). | Confirm **Sense**, not the non-Sense board or Sense Plus. Inspect battery pads and IMU marking. |
| **E-flite EFLB5001S25**, 500 mAh 1S 25C LiPo, JST-RCY | 2 / 1 | Supplies both servos and XIAO from one cell; second pack is spare. | User-provided order image: two batteries, **$28.97 delivered**. [Manufacturer listing](https://www.horizonhobby.com/product/1s-3.7v-500mah-25c-li-po-battery-jst-rcy/EFLB5001S25.html). | Measure connector polarity and dimensions; check condition and voltage before connection. |
| **Pololu 2810 LV Mini MOSFET Slide Switch** | 2 / 1 | Allows XIAO D2 to disconnect the **servo power branch** for low battery and charging; the controller battery branch remains live. | User-provided Pololu order image: two ordered, backordered. [Pololu documentation](https://www.pololu.com/product/2810). | Verify received board is LV 2810; check its VIN/VOUT/GND/ON markings. |
| **Pololu 2181 male JST-RCY lead**, 10 cm, 20 AWG | 2 / 1 | Mates to the battery and creates the split battery connection to XIAO BAT and the switched servo rail. | Same Pololu order, two ordered, backordered. [Pololu product](https://www.pololu.com/product/2181). Pololu order total for switch and leads: **$23.44 delivered**. | Verify polarity with a multimeter before soldering. |
| **MR83ZZ 3 × 8 × 3 mm shielded radial bearing** | **0 bought / 2 used** | Supports the moving link on the side opposite each servo horn; the servo shaft and the passive bearing share one axis. | Proposed, **not ordered**. [Manufacturer dimensions](https://www.ezo-brg.co.jp/english/product/spec.php?eid=00213&unit=mm); [Avid RC 3×8×3 metal-shielded bearing](https://www.avidrc.com/product/p/227/3x8x3-Metal) candidate, listed at $1 each before shipping when checked. | Confirm 3 mm bore, 8 mm OD, 3 mm width and seat fit in the printed pivot coupon. Do not press through the inner race to seat the outer race. |
| **3 × 12 mm smooth stainless-steel dowel pin** | **0 bought / 2 used** | Forms the coaxial journal on each moving link, running in the passive bearing. | Proposed, **not ordered**. [ZYLtech four-pack](https://www.zyltech.com/3mm-x-12mm-steel-dowel-pin-4-pack/) candidate, listed at $1.95 per four-pack before shipping when checked. | Measure pin diameter and fit in bearing and printed blind bore; retain in the printed hub without loading the bearing axially. |
| M2 fasteners: 8 × M2×8 screws, nuts and flat washers for two bodies and two OEM horns; plus two OEM horn center screws | 1 set / 8 sets + 2 OEM screws | Secures the servos to printed mounts and the printed links to their supplied horns. | User reports all components ordered; exact hardware pack and OEM contents not documented. Prior candidate: [25-set M2 pack](https://www.harfington.com/products/p-1076908). | Check the actual servo-ear, 3.5 mm printed frame, washer and nut stack: use M2×10 at the ears if M2×8 lacks full nut engagement. Check horn screw length separately. Do not force an M2 screw into an unknown output thread. |
| Small cable ties, about 6 used | 1 pack / ~6 | Retains the battery at the tunnel end, board, switch and moving-wire strain relief. | User reports all components ordered; exact pack not documented. Prior candidate: [Panduit PLT1M-C](https://www.digikey.com/en/products/detail/panduit-corp/PLT1M-C/280033). | Ensure ties do not compress the battery pouch or snag the moving arm. |
| Three 3D-printed parts: base, middle link, paddle | Print 1 each | Forms the centered structure, encloses each servo in a matching front-and-rear cage, supports the far side of each hinge, and houses the battery in the base tunnel. | [Provisional PTK CAD](cad/README.md). Filament assumed at equipped bench. | Print the full servo-cage coupon after measuring both received servos; verify rear lead exit, both mounting screws and printed rail stiffness before final parts. |
| Solder, flux, insulated wire joints/heat shrink, thin PCB insulation, USB-C data cable | Bench supplies | Joins and insulates the short power split and GPIO connections; cable is for programming and charging. | Assumed on hand or included among user's reported orders; exact quantities unconfirmed. | No exposed conductor near the pouch or moving arm. |

The two order totals visible in screenshots sum to **$52.41**, including the two spare batteries, switch and leads. Other delivered costs and the cost of the proposed pivot additions are unknown, so the actual total against the original $100 target is **not yet verified**. Personal details from receipts are deliberately omitted here.

No external IMU, Raspberry Pi, PCA9685, boost converter or separate charger is in this revision. A bulk capacitor or signal resistors are **diagnostic options only** if the assembled robot exhibits measured voltage dips or signal back-powering; do not add them preemptively. The servo red wires must be fed from the battery through the Pololu switch, **never** from XIAO 3V3 or VBUS. See [power and charging plan](HARDWARE.md).

The PTK family is specified by the [manufacturer's related MG-D page](https://www.ptkhobby.com/en/sys-pd/234.html) for about 5–8.4 V, whereas a 1S cell spans about 4.2 V down to the planned 3.6 V cutoff. The [reference author](https://homemadegarbage.com/rl13) reports actual 3.7 V operation without boost. That makes direct 1S a reasonable experiment for this mechanism, **not a rated operating condition or guaranteed recovery margin**. Incoming bench measurements decide whether the design can stay boost-free.

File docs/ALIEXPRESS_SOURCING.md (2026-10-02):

# Historical AliExpress shopping plan

**Superseded after ordering:** The user reports all parts ordered and chose PTK 7465 MG instead of the FT90M candidate in the old search table below. Use the [current BOM](../BOM.md) and [procurement record](PROCUREMENT_STATUS.md) for Rev A. These search terms are retained only as sourcing history; do not use them to order another servo pair.

AliExpress is an acceptable and potentially convenient **single marketplace checkout** for this project. Several sellers can still be involved, and shipping fees or delivery dates may differ per item. The repository's `BOM.md` preserves exact USA distributor links and the prices verified on 27 September 2026 as a baseline. It does **not** claim those prices apply on AliExpress.

Live AliExpress item pages were not accessible for verification in this work session. The browser's site-safety policy blocked AliExpress before any listing could be checked. The table below gives exact search phrases and acceptance criteria rather than invented product links, seller ratings, availability or prices. Record the chosen product URLs, variant and total delivered price here before ordering.

| Needed | Search phrase | Confirm in the listing before adding to cart |
|---|---|---|
| Controller | `Seeed XIAO nRF52840 Sense 102010469` | Buy the standard **Sense, SKU 102010469**: nRF52840, onboard **LSM6DS3TR-C** IMU, BQ25101 LiPo charger. The plain **102010448** lacks the IMU. **Sense Plus 102010694** retains it but adds unnecessary underside I/O pads; check mount and battery-pad clearance before substituting. Prefer Seeed's official store if identifiable. |
| Two identical servos | `FEETECH FT90M 3V 8.4V 20T` | FT90M model and published 3–8.4 V range; matching **20T** horns and center screws included. Check mounting-flange and output dimensions against `cad/README.md`. Do not silently choose FT90M-FB or generic SG90. |
| 1S battery | `1S 3.7V 500mAh 25C LiPo JST RCY` | Standard LiPo full-charge **4.2 V**, 1S, plausible discharge rating and measured pack dimensions at or below **59.5 × 19 × 7.5 mm** for the current CAD. Confirm connector type and polarity from photos, not just a title. A different dimension or plug requires a drawing/BOM change. |
| Battery mating lead | `JST RCY male pigtail 20AWG` | Mates physically and electrically to the selected battery. Check red/black polarity with a meter before connecting XIAO BAT pads. |
| Servo power switch | `Pololu 2810 mini mosfet slide switch LV` | Buy the **exact Pololu 2810** only if seller identity and board marking can be established. Otherwise use the linked Pololu source in `BOM.md`. A generic mechanical switch changes firmware cutoff behavior; document the substitution first. |
| Fasteners | `M2 x 8mm screws nuts washers set` | At least **8** matching M2×8 screws, nuts and flat washers. The current BOM buys a 25-set kit for spares. Output-horn center screws are separate; confirm them in the servo package or shorten two spare screws after fit measurement. |
| Cable ties | `2.5mm x 100mm nylon cable ties` | At least 6 usable ties and a few spares; the current print has 3.2 mm wide strap passages. |
| Heat shrink if absent | `heat shrink assortment 2mm 3mm 5mm` | Thin sleeves sized for the battery and servo-wire splices. |

**Skip the capacitor and signal resistors for the first order.** If loaded testing later shows power transients or signal back-powering, `BOM.md` lists exact optional parts and the symptoms that justify them.

Use a cart subtotal **with tax and shipping to your ZIP code** to check the $100 target. The $62.83 recommended parts subtotal comes from several USA sellers, not from an AliExpress cart. Do not choose a cheaper battery or servo until its voltage, connector polarity, stall-current behavior and dimensions are credible; those determine whether the robot can rise and charge safely.

Chosen AliExpress item links and checkout total: **not yet verified**. Once selected, add exact item URLs and variant names above so future BOM changes remain reproducible.

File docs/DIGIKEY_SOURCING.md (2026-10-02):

# Historical DigiKey-centered sourcing audit

**Superseded after ordering:** The user reports all parts ordered, with PTK 7465 MG servos and a separate Pololu/battery purchase. The FT90M line and estimates below are historical candidates, not the current [BOM](../BOM.md) or the actual delivered costs. See [procurement status](PROCUREMENT_STATUS.md).

Checked 30 September 2026 for US delivery. This is a sourcing option, not a change to the recommended electrical design or a placed order. Product pages and stock can change before checkout. A DigiKey Marketplace item can ship from a different seller and incur a separate freight charge even though it appears in the same cart.

| BOM function | DigiKey-centered choice | Quantity to buy | What it does / status |
|---|---|---:|---|
| Controller and base IMU | [Seeed XIAO nRF52840 **Sense** 102010469](https://www.digikey.com/en/products/detail/seeed-technology-co-ltd/102010469/16652896) | 1 | **Verified exact BOM item.** Runs the policy, reads its onboard IMU, and charges the 1S pack. Listed at $15.90. |
| Servo-power switch | [Pololu 2810 LV mini MOSFET slide switch](https://www.digikey.com/en/products/detail/pololu/2810/10450360) | 1 | **Verified exact BOM item.** Lets the XIAO disconnect the servo rail; listed at $4.49. DigiKey labels it **Marketplace** and says it ships from Pololu with possible separate shipping. |
| Cable ties | [Panduit PLT1M-C](https://www.digikey.com/en/products/detail/panduit-corp/PLT1M-C/280033) | 10 | **Verified exact BOM item.** Six used, four spare; listed at $2.29 for ten. |
| M2 × 8 mm screws | [BFirst MPMS 002 0008 PH](https://www.digikey.com/en/products/detail/bfirst-industrial/MPMS-002-0008-PH/274950) | 100 minimum | **Same required M2 × 8 pan-head Phillips dimensions**, but DigiKey sells this ordinary metal screw in a 100-piece minimum at $11.42. Eight are used; two more may serve as shortened horn-screw fallbacks. |
| M2 metal hex nuts | [BFirst MHNZ 002 4](https://www.digikey.com/en/products/detail/bfirst-industrial/MHNZ-002-4/274972) | 100 minimum | **Same M2 nut function**, but a 100-piece minimum at $5.30. Eight are used. |
| M2 metal flat washers | [BFirst MFWZ 002](https://www.digikey.com/en/products/detail/bfirst-industrial/MFWZ-002/274977) | 100 minimum | **Same M2 flat-washer function**, but a 100-piece minimum at $3.73. Eight are used. |

The six DigiKey line items total **$43.13 before tax, tariffs and freight** at the displayed quantities and prices. That buys 100 of each fastener, which is more expensive and wasteful than the $7.23 25-set fastener kit in the main BOM. The switch's Marketplace shipping could erase any checkout convenience. If avoiding excess fasteners matters, keep the original kit or select a smaller compatible DigiKey fastener assortment after checking its exact contents.

The remaining off-site parts are:

- **Two FEETECH FT90M servos from AliExpress.** No exact AliExpress listing has been verified; follow the [model, 3–8.4 V rating, 20T horn and screw checks](ALIEXPRESS_SOURCING.md). The AliExpress servo price is not included in the $43.13 figure. Do not substitute a nominal 4.8–6 V SG90 to achieve a one-store cart.
- **One high-discharge 1S battery.** The [E-flite EFLB5001S25 at Vortex Hobbies](https://vortexhobbies.com/flite-500mah-37v-25c-lipo-battery-eflb5001s25-p-70086.html) is the current 500 mAh, 25C, JST-RCY, CAD-sized BOM pack at $11.99. DigiKey does list 500 mAh packs such as [TinyCircuits ASR00035](https://www.digikey.com/en/products/detail/tinycircuits/ASR00035/9808767), but that page specifies a **JST-SH connector and different 31 × 20 × 9.5 mm dimensions** and does not establish the discharge rating needed for two loaded servos. It is **not an approved drop-in substitute**. No matching high-discharge DigiKey pack has been verified.
- **One battery mating lead.** The exact [Pololu 2181 male JST-RCY lead](https://www.pololu.com/product/2181) remains the qualified 20-AWG baseline. DigiKey's [JST A02SYP22KR254SS prewired RCY plug](https://www.digikey.com/en/products/detail/jst-sales-america-inc/A02SYP22KR254SS/9951116) is currently not stocked and has a 1,000-piece minimum. Vortex lists an [Injora XT30-to-male-JST-RCY adapter](https://vortexhobbies.com/injora-xt30-jst-rcy-jst-ph20-trx-style-ec3-battery-adapter-cab-injxt30-jst-ph2-p-257990.html) at $2.99; its XT30 end could be removed, but the listed 60 mm lead has **no published wire gauge**, so it is only a candidate pending wire/connector verification. A generic item titled simply “JST” may use a different connector; match the battery's actual JST-RCY housing and check polarity before soldering.

Thus a **DigiKey + AliExpress + Vortex** three-website cart is plausible **if** the Vortex mating lead passes the connector, gauge and polarity check. The parts with published prices would total **$58.11 before the two AliExpress servos, tax, tariffs and shipping** ($43.13 DigiKey + $11.99 battery + $2.99 candidate lead). This is not a verified delivered price or a complete approved checkout. If the lead is unsuitable, buy the exact Pololu 2181; it adds a vendor unless sourced together with the switch directly from Pololu. For the fewest actual shipments, compare final carts rather than website count.

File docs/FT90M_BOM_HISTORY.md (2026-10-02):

# Historical FT90M purchase estimate — USA delivery, checked 27 September 2026

**Status, 1 October 2026:** The user reports that all parts have been ordered, including **two PTK 7465 MG servos**, not the FT90M servos priced below. This table is retained as a historical estimate and **must not be used as the ordered-parts list or final cost**. See [current BOM](../BOM.md) and [procurement status](PROCUREMENT_STATUS.md). The main CAD and MuJoCo geometry have since been updated to provisional PTK dimensions; this old document's horn and price details have not.

Prices below are historical full purchase quantities, including unused spares. Availability can change. Primary sources are linked directly in each row.

**Source preference:** AliExpress is acceptable and may simplify checkout. The links and prices below are the USA supplier baseline that was actually verified. See the [AliExpress search terms and exact acceptance checks](ALIEXPRESS_SOURCING.md); no AliExpress listing or delivered price has been verified yet. The [controller comparison](CONTROLLER_DECISION.md) explains why the XIAO Sense was chosen and which small electrical parts could be omitted in a more minimal prototype.

For a **DigiKey-centered purchase with servos from AliExpress**, see the [vendor-consolidation audit](DIGIKEY_SOURCING.md). DigiKey can cover the controller, servo-power switch, ties, and M2 fasteners, but the exact high-discharge battery is not yet verified there; the switch is a Pololu Marketplace shipment that may incur separate shipping.

| Buy quantity | Exact item / purchase link | What it does | Used on robot | Extended price | Verification / selection |
|---:|---|---|---:|---:|---|
| 1 | [Seeed XIAO nRF52840 **Sense**, 102010469 — DigiKey](https://www.digikey.com/en/products/detail/seeed-technology-co-ltd/102010469/16652896) | The robot’s brain: runs the trained model and commands both servos. Its **LSM6DS3TR-C IMU is soldered onto this same board**, which mounts on the base. It also **reads battery voltage** through an onboard ADC divider and **charges the 1S battery over USB-C**. Training happens on your computer. | 1 | $15.90 | DigiKey 1597-102010469-ND. This is the selected standard **Sense**, not the non-Sense **102010448**. **Sense Plus 102010694** also has the IMU and charger, but its extra I/O pads are unnecessary here; check underside pad/wiring clearance if substituting it. |
| 2 | [FEETECH FT90M, Nevermore Stealthmax V2 Servo — Beaverton Milestone Hobby](https://beavertonmilestonehobby.com/products/nevermore-stealthmax-v2-servo) — **superseded; not the ordered servo** | Historical actuator choice. | 2 | $17.98 | Historical quote only. The user chose and ordered two PTK 7465 MG servos; exact listing and delivered price have not been provided. |
| 1 | [E-flite EFLB5001S25, 500 mAh 1S 25C — Vortex Hobbies](https://vortexhobbies.com/flite-500mah-37v-25c-lipo-battery-eflb5001s25-p-70086.html) | Stores the energy to run the controller and both servos without a cable. At its connector, power **splits**: one branch to XIAO BAT pads, the other through the servo switch to both servo power leads. No motor current goes through the XIAO. | 1 | $11.99 | Listed in stock for shipping. 59.5 × 19 × 7.5 mm, 14.5 g. Standard 4.2 V full-charge LiPo with JST-RCY; seller excludes Alaska/Hawaii shipment. |
| 1 | [Pololu 2810 Mini MOSFET Slide Switch, **LV**](https://www.pololu.com/product/2810) | Lets the XIAO turn power to both servos on or off—for example, to stop motion when the battery is low. It switches motor power without making the small controller board carry the motors’ current. | 1 | $4.49 | Servo rail only. [Supply status](https://www.pololu.com/product/2810/supply-outlook) lists available units. Physical OFF permits GPIO control; it is **not** a guaranteed manual cutoff. Physical ON forces servo power on. |
| 1 | [Pololu 2181 male JST-RCY plug, 10 cm 20-AWG leads](https://www.pololu.com/product/2181) | Provides a removable connection between the battery and the robot’s wiring. Unplug it for storage or to disconnect all battery power. | 1 | $2.95 | Mates to battery; verify polarity before soldering. Live [supply status](https://www.pololu.com/product/2181/supply-outlook) showed 386 units. |
| 10 | [Panduit PLT1M-C, 2.5 mm × ~99 mm cable ties — DigiKey](https://www.digikey.com/en/products/detail/panduit-corp/PLT1M-C/280033) | Hold the battery guard and electronics in place and secure wires so movement does not pull on solder joints. | 6 + 4 spare | $2.29 | 2 battery guard, 1 controller, 1 switch, 2 strain relief. Sold individually; quantity 10 pricing used. |
| 1 pack | [M2×8 Phillips pan-head screws + nuts + flat/lock washers, 25 sets — Harfington](https://www.harfington.com/products/p-1076908) | Secure the servo bodies to the printed mounts and connect the moving arm pieces to the servo horns—the small arms attached to the motor shafts. Nuts retain the screws; flat washers spread pressure on the plastic. | 8 screw/nut/flat-washer sets | $7.23 | SKU a17040600ux0058; US/USD page listed in stock, dispatch in 24 h. US shipping offered; domestic warehouse origin was not established. |
| | **Recommended Rev A subtotal** | | | **$62.83** | **$37.17 remains for shipping/tax/consumables within $100.** |

**Alternative if joint-angle readback matters, replacing rather than adding to the two FT90Ms:** [FEETECH FT90M-FB at QKits](https://store.qkits.com/rc-robotics/servos/ft90m-fb-micro-size-270-degree-300-degree-2kg-robot-servo-with-feedback.html) was listed in stock at **$8.50 each (USD)**. Its fourth wire exposes an analog angle signal, while the ordinary three servo wires still work as before. This is **not** an SO-100-style smart servo or a proven precision upgrade: it does not provide digital angle/speed/current telemetry, eliminate backlash, or improve the internal positioning loop. The feedback lead can remain insulated and unused for the first policy. [FEETECH specifies](https://www.feetechrc.com/2kg-cm-digital-steering-gear-ft90m-fb.html) 3–8.4 V operation, a 20T spline and a 23.2 × 12 × 25.5 mm case, close to the selected FT90M envelope. Two would make the parts subtotal **$61.85 before shipping/tax**. QKits ships from Canada, and the delivered US price and included horn/screw set have **not** been verified; confirm those before substituting. Do **not** order both pairs merely as insurance. The standard FT90M remains the verified package-with-horns baseline. See the [servo comparison](SERVO_DECISION.md) and [optional feedback wiring plan](../HARDWARE.md#what-the-robot-can-measure).

**No capacitor or signal resistors are required for the first build.** Wire XIAO D0/D1 directly to the servo signal leads, with a shared ground. Keep battery-to-switch-to-servo power wiring short and perform the [loaded power/brownout check](../HARDWARE.md#power-budget-and-brownout-check) before untethered runs. The XIAO's 3V3 and VBUS pins must not carry servo current. If brownouts or servo noise appear, investigate the measured battery and 3V3 rails before adding the optional capacitor below. If a particular servo back-powers from its signal wire while its power is off, first fix firmware power sequencing; add series resistors only after confirming they solve that measured issue.

| Optional diagnostic addition | What it does | Historical purchase price | When to add it |
|---|---|---:|---|
| [Rubycon 1000 µF, 6.3 V capacitor](https://www.digikey.com/en/products/detail/rubycon/6-3YXJ1000M8X11-5/3563358) | Buffers brief voltage dips on the switched servo rail. | $0.51 | If measured battery/servo voltage transients or MCU resets occur despite short, sound power wiring. Observe polarity. |
| 2 × [Yageo 1 kΩ resistors](https://www.digikey.com/en/products/detail/yageo/CFR-25JB-52-1K/96) | Limit accidental signal-wire current into an unpowered servo. | $0.20 total | If testing shows signal back-powering with the actual servos and firmware sequencing cannot fully avoid it. |

**Fewest-parts experiment:** omitting the Pololu switch too leaves the XIAO Sense, two servos, battery, mating lead, ties and fasteners: **$58.34** at the listed USA prices. In that configuration, servos remain electrically connected whenever the pack is plugged in; firmware cannot disconnect their power. Unplug the battery for a complete shutdown, and do not assume USB charging is safe with the servo rail connected and active. The [controller decision](CONTROLLER_DECISION.md) explains the tradeoff. Rev A keeps the switch so the MCU can disable the servos.

If needed: [Adafruit 1649 heat-shrink assortment](https://www.adafruit.com/product/1649), **$4.95**, makes the recommended purchase subtotal **$67.78**. Heat shrink is insulating tubing that tightens around soldered joints when heated, preventing exposed wires from touching and shorting. Use approximately 15 short sleeves, typically 2–3 mm unshrunk for individual joints and larger sizes for the power splice. Existing heat shrink saves a separate vendor order.

## Exact mechanical allocation

| Location | Fasteners / material |
|---|---|
| Servo 1 ears to integral base mount | 2 × M2×8, 2 × M2 nuts, 2 × M2 flat washers |
| Servo 2 ears to middle-link mount | 2 × M2×8, 2 × M2 nuts, 2 × M2 flat washers |
| OEM horn 1 to printed middle-link adapter | 2 × M2×8, 2 × M2 nuts, 2 × M2 flat washers; use opposed lateral slots |
| OEM horn 2 to printed paddle adapter | 2 × M2×8, 2 × M2 nuts, 2 × M2 flat washers; use opposed lateral slots |
| Each OEM horn onto output spline | 1 × OEM center screw; 2 total. Datasheet calls for M2×4. Exact supplied screw count cannot be established from package photo. |
| Center screw fallback | Shorten and deburr 2 spare M2×8 screws from the same kit to the measured required length (nominal 4 mm); check engagement and bottoming. No additional purchase needed. |
| Battery | Printed guard plus 2 ties; feet carry strap tension, not the pouch |
| XIAO | Thin insulating plastic shim beneath PCB plus tie; restrain firmly for reliable IMU orientation |
| Switch | Thin insulating shim plus tie |

The standard FT90M spline is **20-tooth, approximately 3.95 mm**, not a standard-size 25T spline. Use the matching horns shown in the servo package photo. Their actual hole positions and stack height remain a CAD fit check. Drill two suitable horn holes to 2.2 mm to match the adapter slots; trim unused horn arms if needed. Do not drill the spline hub. The hardware pack includes 17 spare complete M2 sets before any center-screw fallback. Split lock washers are supplied but not required against the printed plastic.

## Materials already assumed at an equipped bench

These are explicit exclusions from the purchased-parts subtotal, not hidden robot components:

- Approximately 35–45 g PLA+/PETG including support/waste. Four robot prints: base, middle link, paddle, battery guard.
- Solder and flux; approximately 15 heat-shrink sleeves if already owned.
- Two small thin PET/Kapton insulating shims for PCB undersides, plus a small amount of insulating tape for exposed joints. Mounting must remain firm, not on thick soft foam.
- Wiring: supplied RCY pigtail plus shortened servo leads. Reuse servo-lead offcuts for controller BAT/GND and signal connections. Keep main battery/servo power connections short; use the supplied 20-AWG wire for the battery trunk. Allow moving service loops.
- USB-C **data** cable and ordinary USB 5 V source for programming/charging; laptop, printer, soldering tools, calipers, **DC multimeter**, three thin temporary insulated voltage-sense wires and two clips, small Phillips driver, 2.2 mm drill. The sense wires let you measure BAT and 3V3 without touching moving hardware; see [the procedure](../HARDWARE.md#power-budget-and-brownout-check). A scale, current-limited bench supply and two-channel oscilloscope are useful for further characterization, but not first-purchase robot components.

Do not purchase a Raspberry Pi, PCA9685, separate IMU, buck/boost module, or separate LiPo charger for this architecture. Charge the connected battery through the XIAO's USB-C port with its charger set to approximately 100 mA and the servo rail disabled by firmware. Optional smaller batteries should be chosen only after confirming dimensions, connector, discharge rating and standard 4.2 V charge chemistry.

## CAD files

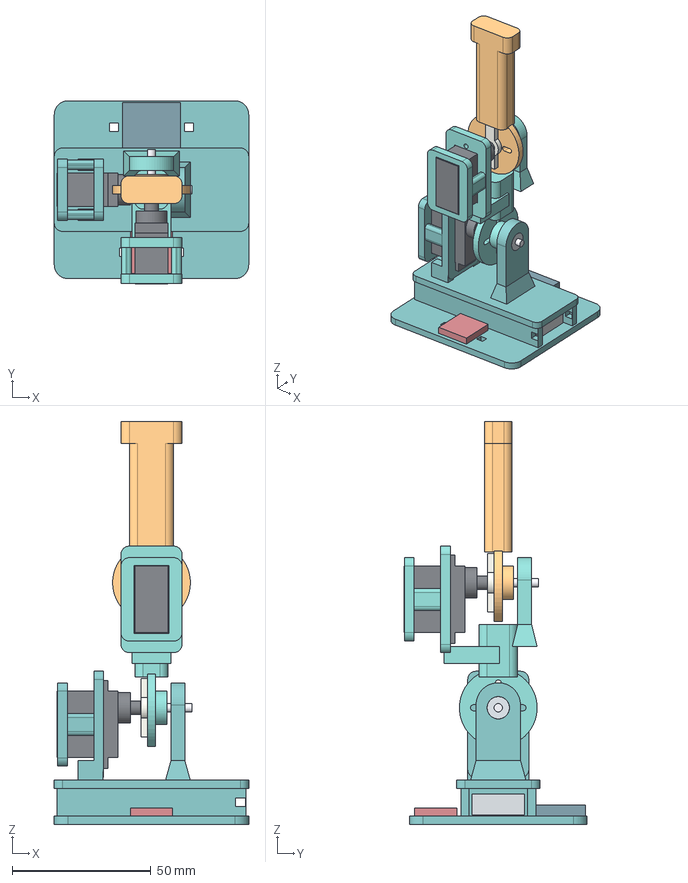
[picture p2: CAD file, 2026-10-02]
cad/assembly.step
70.0 x 66.0 x 145.0 mm
base
middle_link
paddle
servo_1_envelope
servo_2_envelope
horn_1_envelope
horn_2_envelope
bearing_1_envelope
bearing_2_envelope
pin_1_envelope
pin_2_envelope
battery_envelope
controller_envelope
switch_envelope

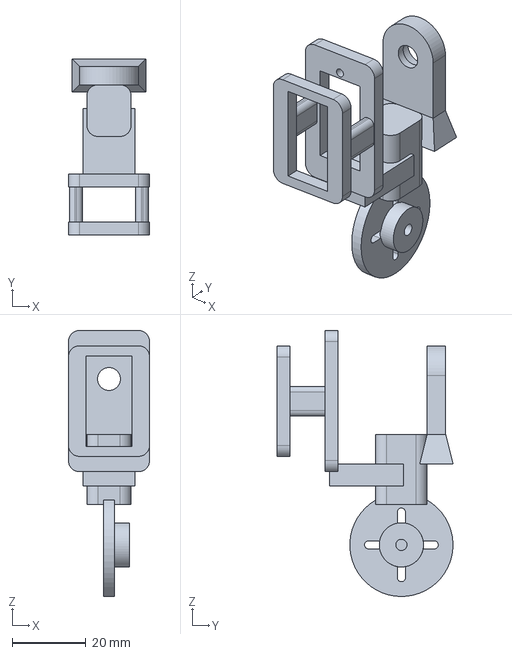
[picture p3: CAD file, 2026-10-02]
cad/middle_link.step
22.0 x 47.8 x 72.2 mm

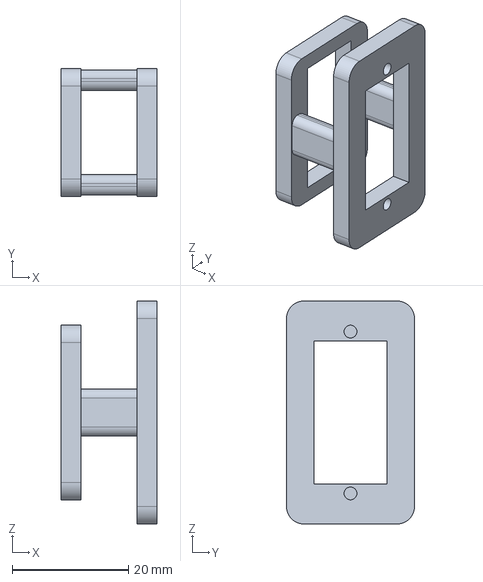
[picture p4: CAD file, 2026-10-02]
cad/servo_mount_fit_coupon.step
16.6 x 22.0 x 38.3 mm

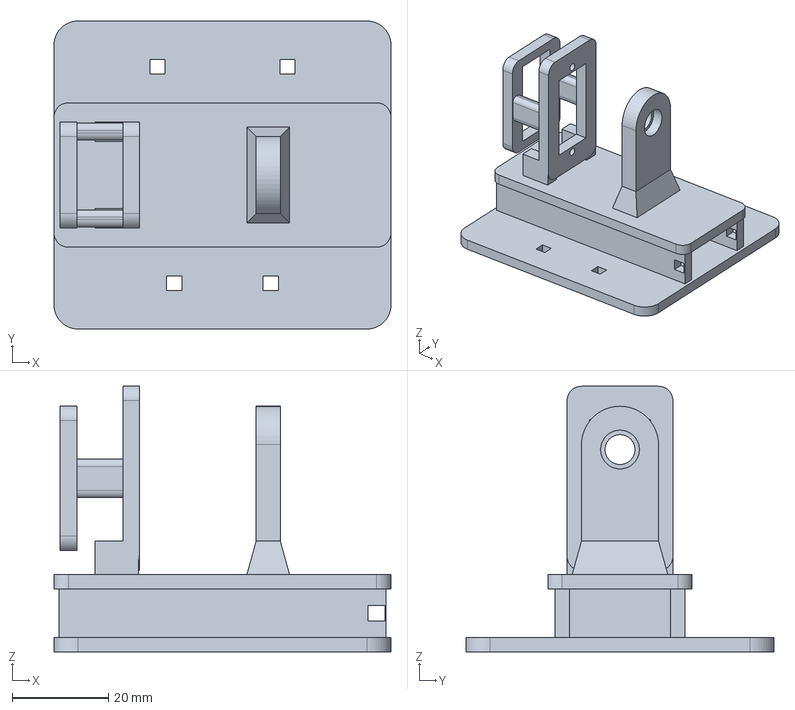
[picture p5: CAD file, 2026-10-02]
cad/base.step
70.0 x 64.0 x 55.1 mm

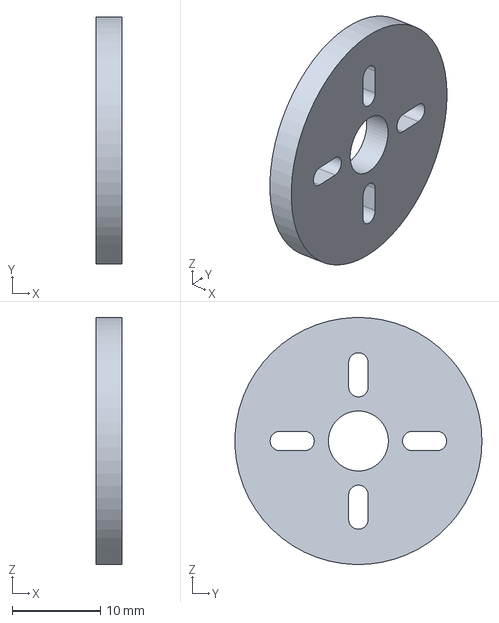
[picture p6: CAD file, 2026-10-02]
cad/horn_fit_coupon.step
3.00 x 28.0 x 28.0 mm

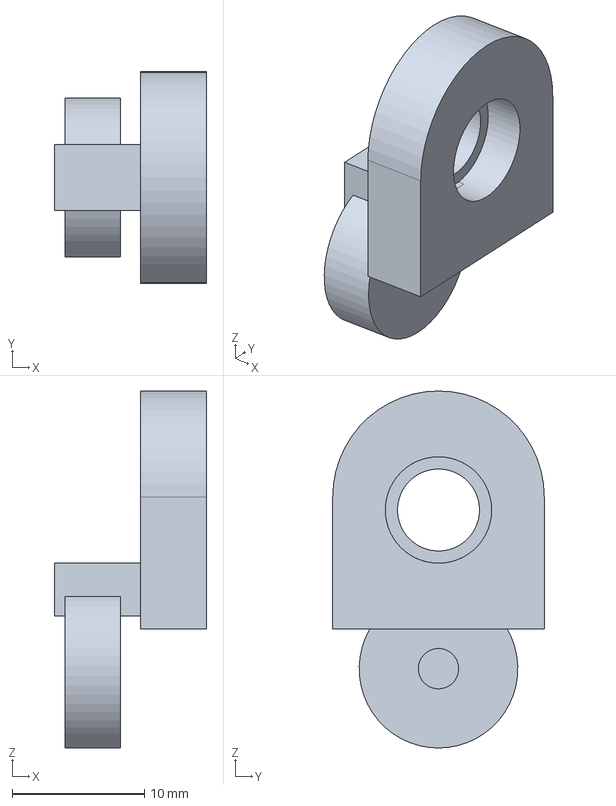
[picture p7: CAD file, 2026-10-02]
cad/pivot_fit_coupon.step
11.5 x 16.0 x 27.0 mm

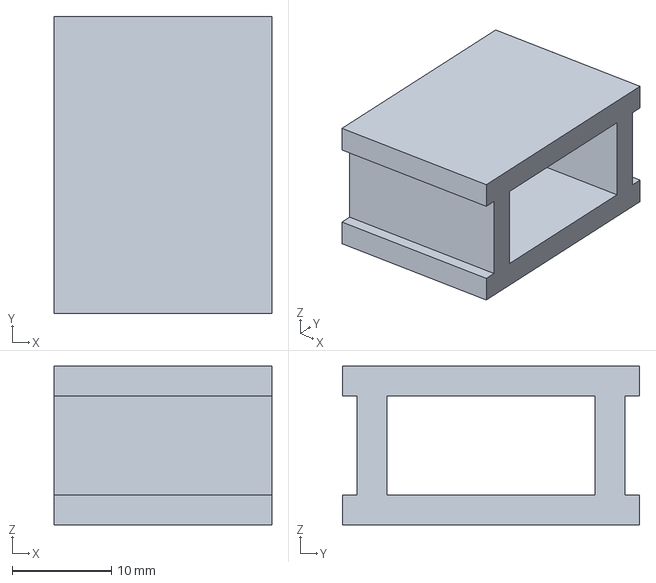
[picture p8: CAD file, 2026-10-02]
cad/battery_tunnel_fit_coupon.step
22.0 x 30.0 x 16.0 mm

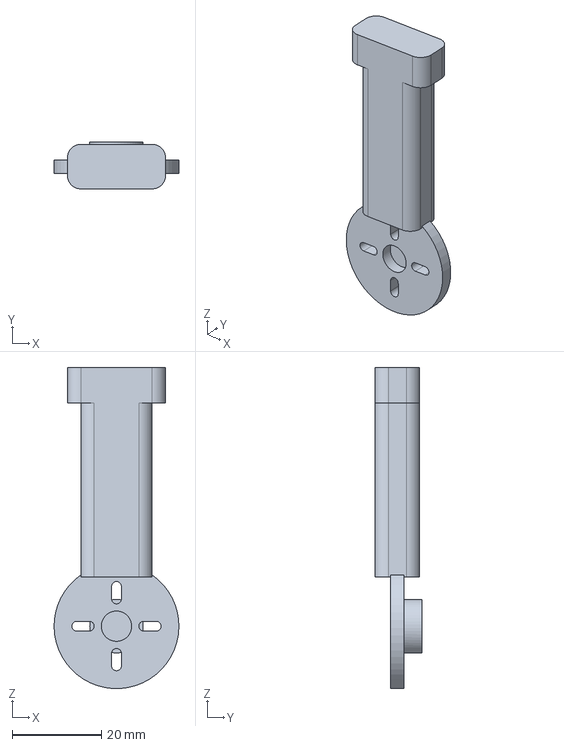
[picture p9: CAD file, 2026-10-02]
cad/paddle.step
28.0 x 10.5 x 72.0 mm

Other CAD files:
cad/base.stl
cad/battery_tunnel_fit_coupon.stl
cad/horn_fit_coupon.stl
cad/middle_link.stl
cad/paddle.stl
cad/pivot_fit_coupon.stl
cad/servo_mount_fit_coupon.stl

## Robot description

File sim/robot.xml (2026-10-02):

<mujoco model="self_righting_arm_ptk7465_provisional">
  <compiler angle="radian"/>
  <option timestep="0.002" integrator="implicitfast" gravity="0 0 -9.81"/>
  <default><geom friction="0.7 0.01 0.001" condim="3" solref="0.008 1"/><joint damping="0.001" armature="0.000002"/></default>
  <worldbody>
    <light pos="0 -1 2"/>
    <geom name="floor" type="plane" size="2 2 0.1" rgba="0.9 0.9 0.9 1"/>
    <body name="base" pos="0 0 0.003">
      <freejoint/>
      <geom name="base_plate" type="box" pos="0 0 0.0015" size="0.035 0.032 0.0015" mass="0.0184" rgba="0.2 0.56 0.57 1"/>
      <geom name="battery_deck" type="box" pos="0 0 0.0145" size="0.035 0.015 0.0015" mass="0.0055" rgba="0.2 0.56 0.57 1"/>
      <geom type="box" pos="0 -0.012 0.008" size="0.034 0.0015 0.005" mass="0.002" rgba="0.2 0.56 0.57 1"/>
      <geom type="box" pos="0 0.012 0.008" size="0.034 0.0015 0.005" mass="0.002" rgba="0.2 0.56 0.57 1"/>
      <geom type="box" pos="0.0095 0 0.034" size="0.0025 0.008 0.018" mass="0.003" rgba="0.2 0.56 0.57 1"/>
      <geom type="box" pos="-0.023 0 0.036" size="0.011 0.006 0.01195" mass="0.013" rgba="0.15 0.15 0.15 1"/>
      <geom type="box" pos="0 0 0.00725" size="0.02975 0.0095 0.00375" mass="0.0145" rgba="0.6 0.6 0.6 1"/>
      <geom type="box" pos="0 0.0225 0.005" size="0.0105 0.0089 0.002" mass="0.004" rgba="0.2 0.3 0.4 1"/>
      <geom type="box" pos="0 -0.0225 0.0045" size="0.00762 0.00762 0.0015" mass="0.0015" rgba="0.6 0.2 0.2 1"/>
      <site name="imu" pos="0 0.0225 0.005" size="0.001"/>
      <body name="middle" pos="0 0 0.042">
        <joint name="j1" type="hinge" axis="1 0 0" range="-1.3963 1.3963"/>
        <geom type="box" pos="0 0 0.0205" size="0.006 0.007 0.0095" mass="0.0075" rgba="0.26 0.69 0.66 1"/>
        <geom type="box" pos="0 -0.0095 0.019" size="0.007 0.010 0.003" mass="0.003" rgba="0.26 0.69 0.66 1"/>
        <geom type="box" pos="0 0.0095 0.037" size="0.008 0.0025 0.014" mass="0.003" rgba="0.26 0.69 0.66 1"/>
        <geom type="box" pos="0 -0.023 0.039" size="0.006 0.011 0.01195" mass="0.013" rgba="0.15 0.15 0.15 1"/>
        <body name="paddle" pos="0 0 0.045">
          <joint name="j2" type="hinge" axis="0 1 0" range="-1.3963 1.3963"/>
          <geom type="box" pos="0 0 0.0305" size="0.008 0.005 0.0195" mass="0.009" rgba="0.95 0.64 0.25 1"/>
          <geom type="box" pos="0 0 0.054" size="0.011 0.005 0.004" mass="0.002" rgba="0.95 0.64 0.25 1"/>
        </body>
      </body>
    </body>
  </worldbody>
  <actuator><motor joint="j1" ctrlrange="-0.07 0.07"/><motor joint="j2" ctrlrange="-0.07 0.07"/></actuator>
  <sensor><gyro name="gyro" site="imu"/><accelerometer name="accel" site="imu"/></sensor>
</mujoco>

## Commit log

2026-09-29 Add self-righting robot Rev A design package
    [assembly.step, base.step, base.stl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]
2026-09-30 Make passive power components optional in Rev A
2026-09-30 Document servo power split and brownout test
2026-09-30 Explain voltage measurement and low-cell limits
2026-09-30 Document onboard battery sensing and USB charging
2026-09-30 Clarify servo power and add matching 1C charger
2026-09-30 Restore onboard charging and document runtime estimate
2026-10-01 Document sensor inventory and policy observability
2026-10-01 Explain servo dynamics calibration for RL training
2026-10-01 Document optional FT90M-FB feedback servo substitution
2026-10-01 Clarify SO-100 smart servo tradeoffs
2026-10-02 Record ordered hardware and PTK servo selection
2026-10-02 Adapt Rev A design to provisional PTK 7465 MG geometry
    [assembly.step, base.step, base.stl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]
2026-10-02 Add outboard bearing supports to both arm joints
    [assembly.step, base.step, base.stl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]
2026-10-02 Center and reinforce self-righting arm CAD
    [assembly.step, base.step, base.stl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]
2026-10-02 Add matching two-sided servo cages to arm CAD
    [assembly.step, base.step, base.stl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]
2026-10-23 Add Rev A electrical wiring schematic and guide
2026-10-23 Show complete wiring and physical power buses
2026-10-23 Document compact power bus harness options
2026-10-23 Use Pololu output pads as servo positive bus
2026-10-23 Reshape CAD toward reference robot silhouette
2026-10-24 Rebuild arm CAD around reference open bracket layout
2026-10-31 Add phone-friendly power and signal wiring visuals
2026-10-31 Add disarmed servo centering firmware and native macOS setup
2026-10-31 Record initial electrical measurements and unresolved switch output
2026-10-31 Clarify floating switch output and record physical slide test
2026-10-31 Record supervised three-second power-only test acknowledgements
2026-10-31 Record unexpected VOUT response and pause servo commissioning
2026-10-31 Add bounded unloaded servo jogs and record neutral setup
2026-10-31 Add small assembled-joint tests and record successful motion
2026-10-31 Simplify Rev B wiring to direct battery power without Pololu
2026-10-31 Treat generated PDF schematics as binary artifacts
2026-10-31 Add simultaneous two-joint dance and commission direct wiring
2026-10-31 Add fine PWM, battery motion guard and continuous fast dance
2026-11-01 Import final Onshape assembly and add interactive joint review
2026-11-01 Inspect third Onshape export and record remaining shaft offset
2026-11-01 Estimate printed masses from slicer toolpaths and record PCB priority
2026-11-01 Record future onboard battery-status LED idea
2026-11-01 Train and validate simulation recovery actor and compile XIAO probe
2026-11-01 Prepare sensor-only XIAO commissioning firmware and IMU recorder
2026-11-02 Bring up onboard IMU and record provisional sensor mounting calibration
2026-11-02 Validate motor-disabled policy shadow with calibrated IMU filter
2026-11-02 Add supervised visual servo pulse-to-angle calibration
2026-11-02 Record visual servo angle mapping and confirmed CAD pulse signs
2026-11-02 Document robot operation, battery checks and charging
2026-11-03 Add one-piece electronics cup CAD for fit printing
2026-11-03 Package single-Pololu enclosure fit print and PWM-off charging mode
2026-11-03 Revise enclosure fit with low PSA lands, connected ribs and rounded bottom
2026-11-04 Update enclosure simulation, recovery experiments and complete wiring guide
2026-11-04 Document future integrated robot controller and power PCB
2026-11-04 Tighten USB opening and move battery toward enclosure wall
2026-11-07 Route lower servo PWM to D8 and upper to D7
2026-11-07 Stop PWM after one minute of IMU inactivity until reboot
2026-11-07 Train and deploy C3 enclosure recovery policy
2026-11-08 Deploy faster C3 recovery with varied stalled-attempt sweeps
2026-11-10 Replace obsolete CAD downloads with current C3 robot assembly
2026-11-10 Show current robot and enclosure previews in CAD downloads guide
